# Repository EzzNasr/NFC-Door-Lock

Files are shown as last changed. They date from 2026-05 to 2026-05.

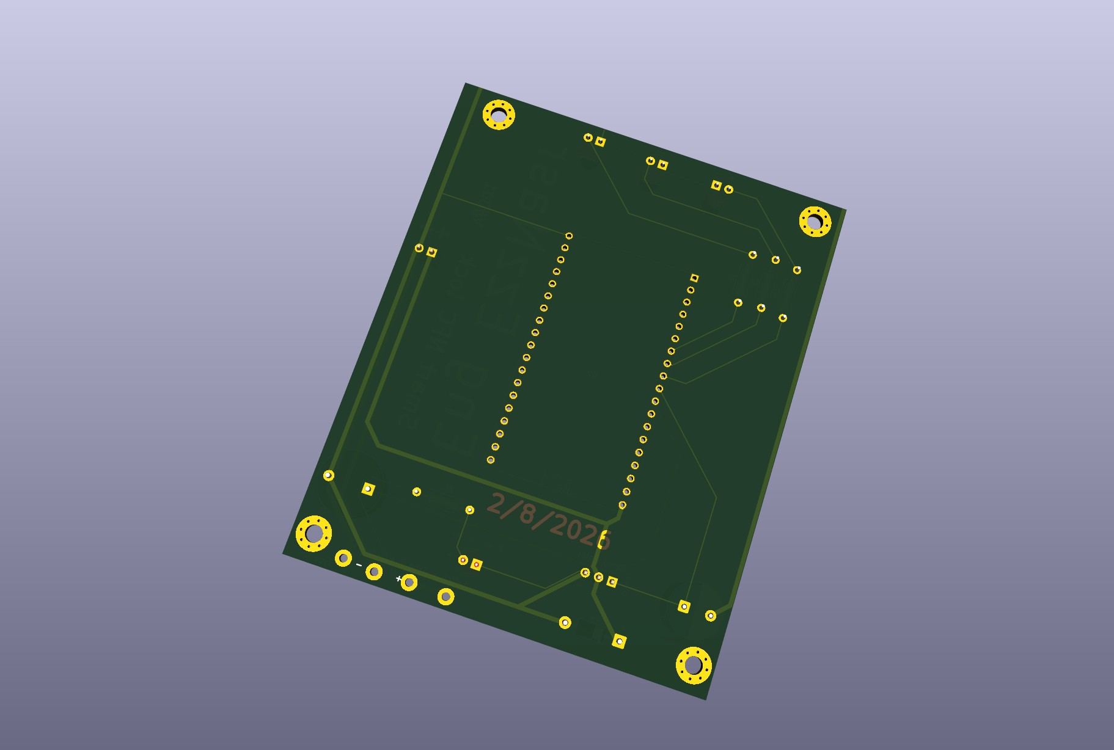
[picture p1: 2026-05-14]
PCB/iterations/third/2.jpg

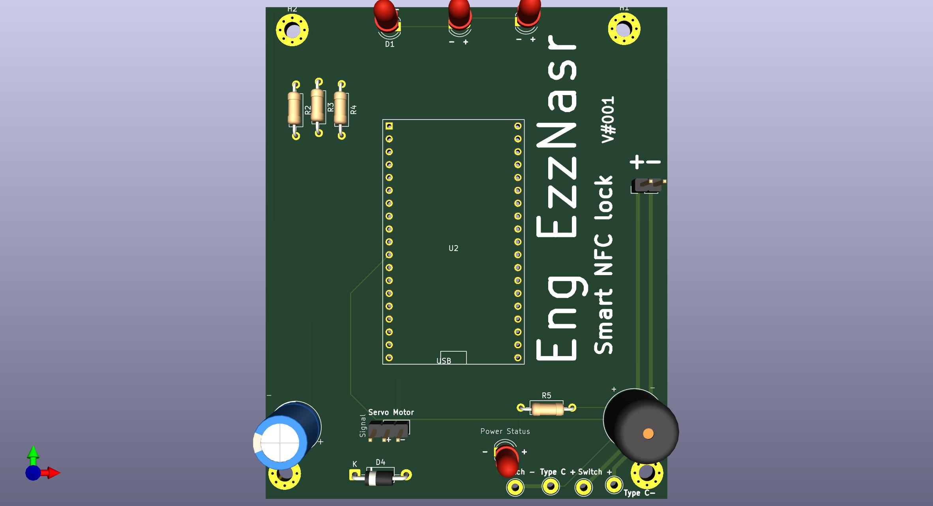
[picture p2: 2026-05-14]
PCB/iterations/third/z.jpg

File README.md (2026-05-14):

ESP32 PN532 NFC Master Tester

I built this project to solve a massive headache: getting the PN532 NFC module to reliably talk to an ESP32 without crashing, hanging, or timing out. If you have ever tried to hook these two up and got hit with the infamous "i2cRead returned Error 263" message, this code is exactly what you need.

What it does (The Big Picture)
At its core, this is a diagnostic tool and a rock-solid starting point for NFC projects. When you connect a card reader to a microcontroller brain, they have to speak the same language. Often, because of cheap clone parts or confusing wiring diagrams, they just ignore each other.

This code acts as a bridge. It lets you easily flip between different communication methods until the devices finally connect. Instead of guessing if your board is dead or if your code is wrong, this setup actively tells you what to fix so you can get back to actually scanning RFID tags and cards.

How it works (The Technical Details)
Under the hood, this is a dual-mode PlatformIO project written in C++. It specifically targets the hardware quirks of the ESP32 and those common red PN532 breakout boards.

The main reason I2C fails on these boards (giving you Error 263) is a hardware flaw: they often lack the proper pull-up resistors on the data lines. The ESP32 sends a signal, the voltage drops too low, and it times out waiting for an acknowledgment.

This project bypasses that hardware flaw entirely by giving you a one-line software toggle between standard I2C and High-Speed UART (HSU). If I2C refuses to work, you just comment out a single line of code. The script seamlessly reconfigures the system to use the ESP32 Hardware Serial (RX2/TX2). HSU forces a direct, robust data stream that completely ignores the I2C resistor issues. The code also implements non-blocking retries, ensuring your main loop never hangs indefinitely while polling for a card.

Hardware Configuration Rules
The absolute most critical part of this setup is matching the physical DIP switches on the reader to your code. If both switches are ON, the board enters a reserved state and disables communication entirely.

If you are using I2C Mode: Switch 1 must be ON, and Switch 2 must be OFF. Connect SDA to GPIO 21 and SCL to GPIO 22.

If you are using HSU / UART Mode: Both switches must be OFF. Cross your serial lines by connecting the PN532 TX to ESP32 RX (GPIO 16) and PN532 RX to ESP32 TX (GPIO 17).

Just select your mode at the top of the file, flash the board, and open the serial monitor. The code will output exactly how your physical switches and wires should be configured based on the mode you chose, making troubleshooting essentially foolproof.

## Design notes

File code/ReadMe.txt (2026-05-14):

Before you upload your code, you’ll need to install the RFID library which is bundled with the sketch zip file. This is easily done in your Arduino IDE by clicking on Sketch -> Include Library -> Add .ZIP Library and the selecting the zipped library file.

In the code we first include the required libraries and then set up the sensor object and an array to return the read tag serial number.

The next array and its associated size is used to store the serial numbers for all of the tags which you’d like to grant access to. You’ll need to find and update these numbers using the serial monitor by uploading this code and then scanning your tags. The Serial monitor will display the tag’s serial number and then state that access is denied. Copy this number into the array accessGranted, update the array size (number of tags registered) and then re-upload the code. You could also write a short section to enable you to register a new tag by pushing a button inside the sensor component box or inside the door for example.

We then set up the servo object and it’s travel limits. You may need to make adjustments to these limits to get your servo to move through it’s full range without over-travelling in either direction.

In the setup code, we connect to the RFID sensor, define the LED pins and then run through a quick LED flash startup sequence before making sure that the lock is in the locked position. You can remove the Serial monitor output lines in the code in your final version, these are just useful for registering your tags and debugging the system when you first assemble it.

We then run through the loop which waits for a card or tag to be scanned, determines its serial number and then passes this serial number through to a function called checkAccess to verify whether the tag number can grant access or not.

The checkAccess function simply takes the read tag number and then cycles through the array of accepted numbers to see if it is an accepted tag. If a match is found then the green LED is flashed and the lock is either opened or closed, depending on the previous state. If the tag number is not found in the array then the red LED is flashed and the lock is not opened.

There are a couple of ways to make this lock a bit more secure if you’re actually going to be using it to secure a room or cupboard.

Start by replacing the 3D printed lock with a proper metal lock from a hardware store. Make sure that you have a solid connection between the lock and the servo and try to position the servo such that the arm is in line with the push-rod and the head of the slider when it is in the locked position. This will ensure that you can’t slip a thin object through the gap in the door and try to push the slider open, you’ll be pushing against the centre of the servo and not relying on the torque provided by the servo to keep the slider in place.

Next, place as few of the electronic components outside as possible. It is better to have the actual Arduino and servo connection inside the room or box and place only the RFID sensor and LEDs outside. It’s much more difficult to trick the Arduino into opening the lock using the RFID sensor connection than it is to simply provide a PWM signal to the servo to unlock the door.

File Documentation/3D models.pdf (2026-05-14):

# Design & Implementation of an NFC-Based Smart Drawer Lock

## A Hybrid Authentication System (UID + APDU) with Mechanical Actuation

### Ezz Nasr

Engineering Specialization: Computer Communications

### February 9, 2026

# Contents

1 System Overview | 2
2 Hardware Specifications | 3
3 Circuit Design, Wiring, and Electrical Hardening | 5
4 Hybrid Authentication Engine | 8
5 Apple Ecosystem Integration | 11
6 Phased Implementation Plan | 12

# Chapter 1 System Overview

## 1.1 Project Abstract

This project engineers a secure, invisible locking mechanism for a desk drawer using an ESP32 microcontroller. Unlike standard hobbyist locks, this system employs a Hybrid Authentication Engine. It provides instant access via standard NTAG213 tokens and encrypted, high-security access via EMV banking cards (Visa/-Mastercard) using APDU command parsing. Additionally, it integrates with the Apple ecosystem via a ”Controller-based” approach using iOS Shortcuts and Wi-Fi webhooks.

## 1.2 System Architecture Diagram

The system relies on a central controller (ESP32) managing peripherals via I2C (Reader) and GPIO (Actuator). The entire system is now powered by a single, stable 5V source.

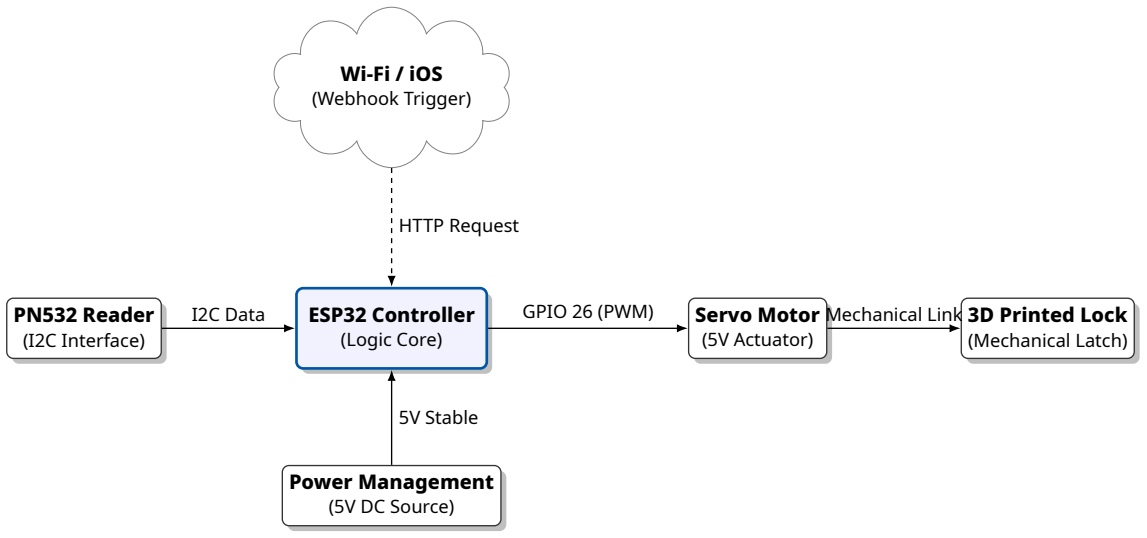
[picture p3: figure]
ESP32 Controller (Logic Core); PN532 Reader (I2C Interface); Servo Motor (5V Actuator); 3D Printed Lock (Mechanical Latch); Power Management (5V DC Source); Wi-Fi / iOS (Webhook Trigger); I2C Data; GPIO 26 (PWM); Mechanical Link; 5V Stable; HTTP Request

Figure 1.1: System Architecture Diagram

# Chapter 2 Hardware Specifications

## 2.1 Bill of Materials (BOM)

Qty Component | Description / Specification
1 ESP32 Dev Module | WROOM-32 (38-pin recommended)
1 PN532 NFC Module | Must support I2C mode
1 Servo Motor | SG90 (Plastic Gear) for light duty OR
MG996R (Metal Gear) for heavy security
1 5V Power Supply | 5V 2A USB Adapter will be enough
tbh
1 Capacitor (C1) | 470µF or 1000µF, 10V+ Electrolytic-
to | avoid | V-Drop | Restarts-
(Brownout)
1 Diode (D1) | (EMF Protection)
1 Piezo Buzzer | 5V Active Buzzer (for auditory feed-
back)
1 Enclosure Materials PLA/PETG Filament for 3D printed lock body
- | Wiring | Jumper wires (Female-Female),
Breadboard or PCB
4 LEDs | For visual sequences
1 Break out Type C board for seamless power connection ( only if PCB)
1 rocker switch | For Emergency power Off

Table 2.1: Complete Bill of Materials including electrical safety components

## 2.2 Microcontroller: ESP32-WROOM-32

The brain of the operation. Selected for its dual-core architecture (allowing network tasks to run without blocking NFC polling).
DATASHEET SUMMARY: ESP-WROOM-32
Operating Voltage: | 2.2V – 3.6V (Requires 3.3V Regulated)
Input Voltage (VIN): | 5V (Directly from Power Source)
Wi-Fi Protocol: | 802.11 b/g/n (Up to 150 Mbps)
Bluetooth: | v4.2 BR/EDR and BLE
GPIO Logic Level: | 3.3V (NOT 5V Tolerant)
Max Current per GPIO: | 12 mA (Source), 20 mA (Sink)

## 2.3 NFC Reader: PN532 (The ”Red Board”)

The most capable NFC chip for hobbyist use, supporting full Read/Write and Card Emulation.
DATASHEET SUMMARY: NXP PN532
Frequency: | 13.56 MHz (High Frequency)
Range: | 5cm – 7cm (Antenna Dependent)
Operating Voltage: | 2.7V – 5.5V
Current Consumption: | Typ. 100mA (Active), 30mA (Standby)

## 2.4 Actuator: Micro Servo Motor (SG90/MG996R)

The servo motor provides precise, low-power mechanical actuation for the 3D-printed lock. The choice between SG90 (micro) and MG996R (metal gear, high torque) depends on the mechanical resistance of the 3D-printed mechanism, in today’s project i decided to use a light 3D printed lock as it made for domestic use and would be sufficient
DATASHEET SUMMARY: SG90/MG996R SERVO
Operating Voltage: | 4.8V – 6.0V (5V Nominal)
Control Signal: | Pulse Width Modulation (PWM)
Idle Current: | ≈ 10 mA
Stall Current (SG90): | ≈ 600 mA
Stall Current (MG996R): | ≈ 2.5 A
Actuation: | Rotational (typically 0◦ to 180◦ )

# Chapter 3 Circuit Design, Wiring, and Electrical Hardening

## 3.1 Exact Wiring Table

The system is simplified to run entirely on a single 5V power rail. The servo motor’s power lines MUST be connected directly to the 5V power source, not through the ESP32’s on-board regulator, to prevent brownouts. an Alternate approach would be using a commercially available solenoid lock, although it would require a step up converter

Component | Pin Mapping
Power Input | 5V DC Adapter → Common 5V Rail 5V DC Adapter → Common GND Rail
ESP32 Power | Common 5V Rail → ESP32 VIN Common GND Rail → ESP32 GND
NFC Reader (I2C) | ESP32 3V3 → PN532 VCC ESP32 GND → PN532 GND ESP32 GPIO 21 → PN532 SDA ESP32 GPIO 22 → PN532 SCL
Servo Motor | Common 5V Rail → Servo VCC (Red Wire) Common GND Rail → Servo GND (Brown/Black Wire) ESP32 GPIO 26 → Servo Signal (Orange/Yellow Wire)

Feedback (Buzzer) ESP32 GPIO 18 → Buzzer (+)
| ESP32 GND → Buzzer (-)
Table 3.1: System Pinout Configuration on the bread Board

## 3.2 Detailed Wiring Diagram with Electrical Hardening

The servo motor is an inductive load and can introduce noise and voltage spikes into the power rail, potentially causing the ESP32 to reset (brownout). The following schematic uses standard electrical symbols to illustrate the critical components required to protect the microcontroller and ensure stable operation.

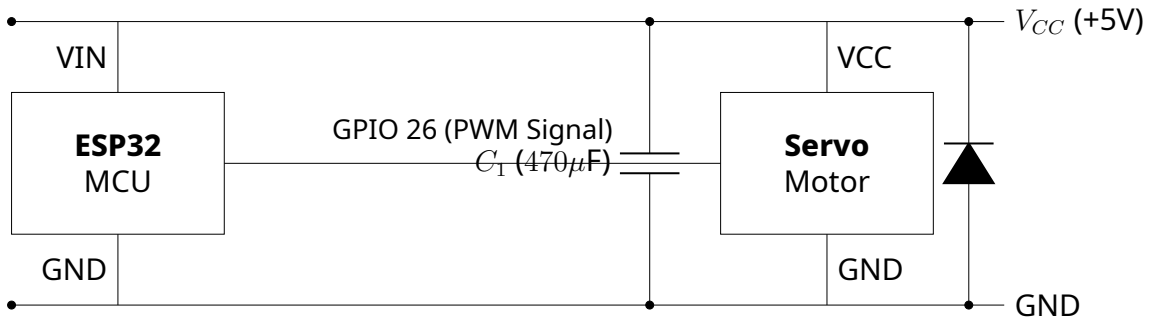
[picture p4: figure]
VCC (+5V); GND; ESP32 MCU; VIN; Servo Motor; VCC; GPIO 26 (PWM Signal) C1 (470µF)

Figure 3.1: Schematic of Circuit with precautions against EMF

## 3.3 Electrical Safety and Component Hardening

The transition to a servo motor, while simplifying the power supply, introduces new electrical noise challenges due to the motor’s rapid current draw and back-EMF.
- Bulk Capacitor (C1): A large electrolytic capacitor (e.g., 470 µF, 10V) must be placed as close as possible to the servo motor’s power pins (VCC and GND).
ℹ Logic Insight
Purpose: Servos draw large, short bursts of current (up to 2.5A for an MG996R) when they start moving or encounter resistance. This causes a momentary voltage drop (brownout) on the 5V rail, which can reset the ESP32. The capacitor acts as a local, high-speed energy reservoir to supply these current spikes, isolating the ESP32 from the noise.
- Diode should be placed across the 5V power rail, with the cathode (banded side) connected to VCC and the anode to GND, acting as an OC when the servo is ideal, and being a SC to dissipate the excess current generated due to the EMF

ℹ Logic Insight
Purpose: Although a servo is controlled by a closed-loop circuit, its internal DC motor is an inductive load. When the motor is suddenly stopped or reversed, it generates a voltage spike (back-EMF) that can exceed the supply voltage and damage the ESP32 or the power supply. The reverse-biased diode provides a safe path for this transient current to recirculate, clamping the voltage spike and dissipating the energy harmlessly.
- Power Rail Separation: The servo’s VCC and GND lines MUST be connected directly to the main 5V power source, not to the 5V pin on the ESP32 board. This ensures the high current draw bypasses the thin traces and potentially weak regulators on the microcontroller board.

## 3.4 Emergency Fail-Safe Mechanism

a drawback of the current implementation is that in the event of power loss, the door or drawer locked wouldn’t be accessible at all.
proposed solutions :
- 1- make a mechanical way to bypass the ESP32 entirely ( like physically moving the latch with a string )
- 2- implementing a battery solution for emergencies.
we will not be diving into these solutions at this time.

# Chapter 4 Hybrid Authentication Engine

This section details the ”If/Else” logic that allows the system to differentiate between a simple tag and a complex credit card.

## 4.1 The Logic Flow

The code must implement a non-blocking state machine.
- Path A (Fast): Reads the UID. If it matches the whitelist, UNLOCK immediately (Time: < 200ms).
- Path B (Slow): If UID is random/unrecognized, assume it is a Banking Card. Initiate APDU handshake to extract the PAN (Primary Account Number). (Time: 1.5 – 2.0s).
ℹ Logic Insight
ID is short for Uniqe ID , that is present in NFC chips such as the normal cards that come with the NFC reader or Credit Cards

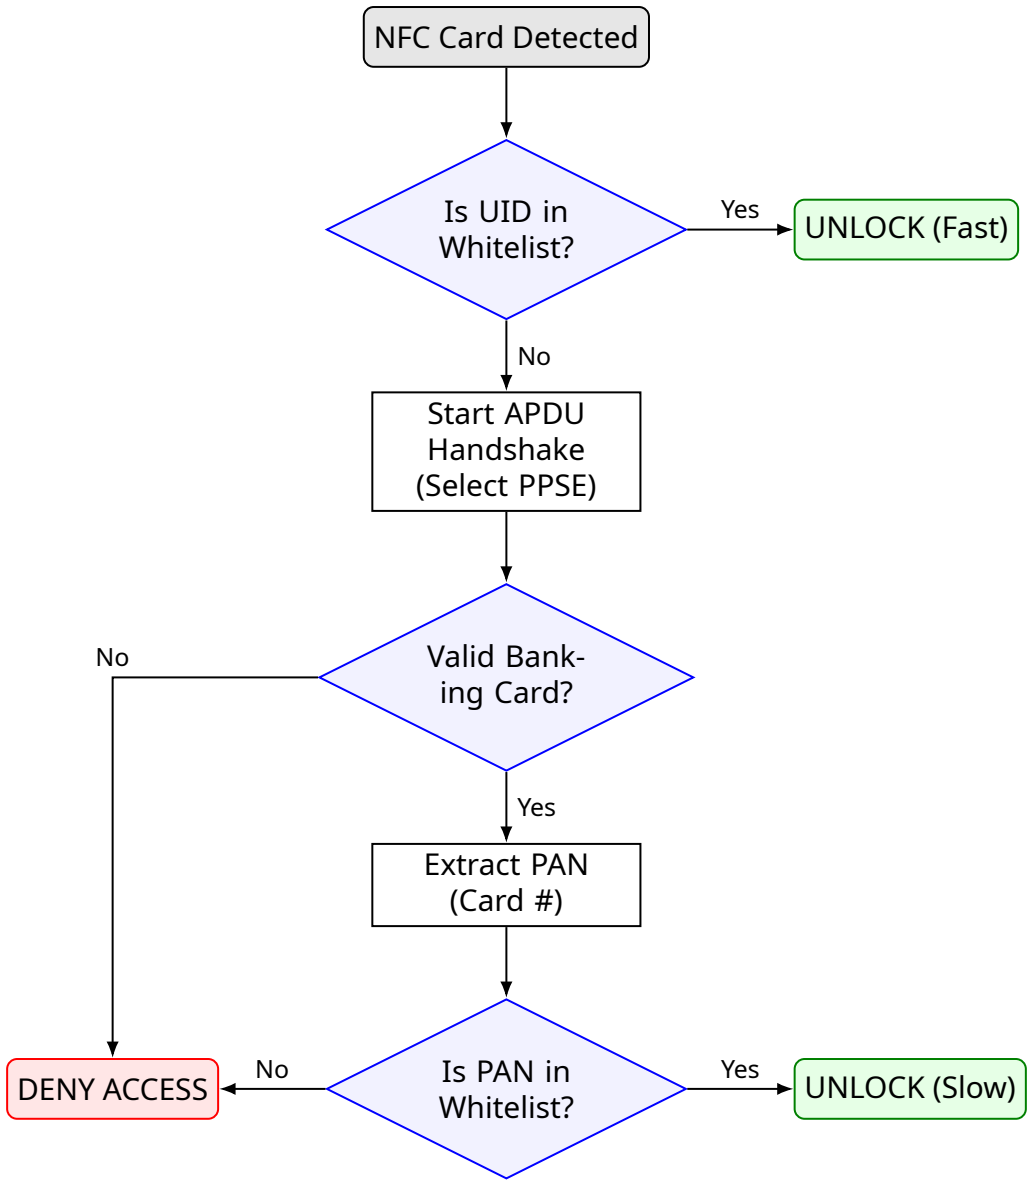
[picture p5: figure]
NFC Card Detected; Is UID in; Whitelist?; UNLOCK (Fast); Start APDU Handshake (Select PPSE); Valid Bank- ing Card?; Extract PAN (Card #); Is PAN in; Whitelist? DENY ACCESS; UNLOCK (Slow); Yes

Figure 4.1: Hybrid Authentication Logic Flowchart

## 4.2 The Credit Card Handshake (Technical Detail)

Why does it take 2 seconds? Because we are not just reading a serial number; we are negotiating a session.
1. SELECT PPSE (2PAY.SYS.DDF01): The ESP32 asks the card, ”What payment methods do you support?”
2. SELECT AID: The card replies with a list (e.g., Visa ID: A0000000031010). The ESP32 must select the specific App ID.
3. GET PROCESSING OPTIONS (GPO): The ESP32 asks for the file processing structure.

4. READ RECORD: The ESP32 reads the specific memory block containing the card number (PAN).

# Chapter 5 Apple Ecosystem Integration

## 5.1 The ”Controller” vs. ”Key” Concept

//
ℹ Logic Insight
Constraint: Apple devices restrict direct NFC UID access (CoreNFC limitations). We cannot use the iPhone as a passive ”Key.”
Solution: We invert the relationship. The iPhone acts as the ”Controller.” It reads a passive tag/sticker on the desk and sends a command to the lock via Siri Shortcuts.
similar logic can be applied for an android for to achieve the same results

## 5.2 Implementation Steps

1. Hardware: Stick a standard NTAG213 sticker on top of the drawer (hidden or visible).
2. ESP32 Setup: Program the ESP32 to listen for a specific HTTP Webhook (e.g.,
http://192.168.1.50/unlock).
3. iOS Shortcut: Create a ”Personal Automation” in the Shortcuts app:
- Trigger: ”When I tap NFC Tag...”
- Action: ”Get Contents of URL” → (Your ESP32 IP).
- Option: ”Run without asking” (Enabled).

# Chapter 6 Phased Implementation Plan

## Phase 1: The ”Open Air” Prototype and Mechanical Design

- Assemble components on a breadboard, including the servo and electrical hardening components (C1, D1).
- Goal: Read a standard tag UID via Serial Monitor and successfully actuate the servo motor between its locked and unlocked positions.
- Verification: Ensure the servo moves smoothly and the ESP32 does not reset during actuation.
- Mechanical Design: Finalize the 3D-printed lock mechanism, ensuring minimal friction and incorporating the mechanical override.

## Phase 2: Power & Electrical Validation

- Connect the 5V supply and test the system under load.
- Load Test: Run the servo continuously for 5 minutes. Monitor the 5V rail voltage with an oscilloscope or multimeter to ensure stability (no drops below 4.5V).
- Code Safety: Implement the ”Watchdog Timer” (Force servo to stop after 5 seconds of continuous running) to prevent motor burnout or mechanical binding.

## Phase 3: The Hybrid Code Integration

- Introduce the APDU library.
- Goal: Successfully read a Credit Card PAN and output it to Serial.
- UX Tuning: Tune the buzzer to beep during the read process so the user doesn’t pull the card away too early.

## Phase 4: Enclosure & Final Mounting

- 3D print the final housing and mechanical parts.
- Critical Step: Install the Mechanical Override (Fail-Safe).
- Mount the reader using nylon screws (no metal!) to preserve antenna tuning.
//
ℹ Logic Insight
Note that along with this file there will be a Code file along with the 3D files ready to print for the convenience of the reader
for those of you who will be building the PCB board
- Gerber Files will be provided
- 3D visualizations will be provided
- schematics will be provided

- this PCB implementation features alternative power rails in Case of failure of the USB C port you may use the pins on the top right indicated by + and -
- we are using a 2 layer PCB measuring under 100mm x 100mm such that the fabrication costs would be relatively attainable
- in addition to being able to route the traces easily
- it was also a concinnous decision not to make the component any closer than this such that it would be relatively easy for a first timer to solder them on their own

in Case you are having trouble locating the files,
it would be my pleasure to answer your questions at ezznasrone@gmail.com

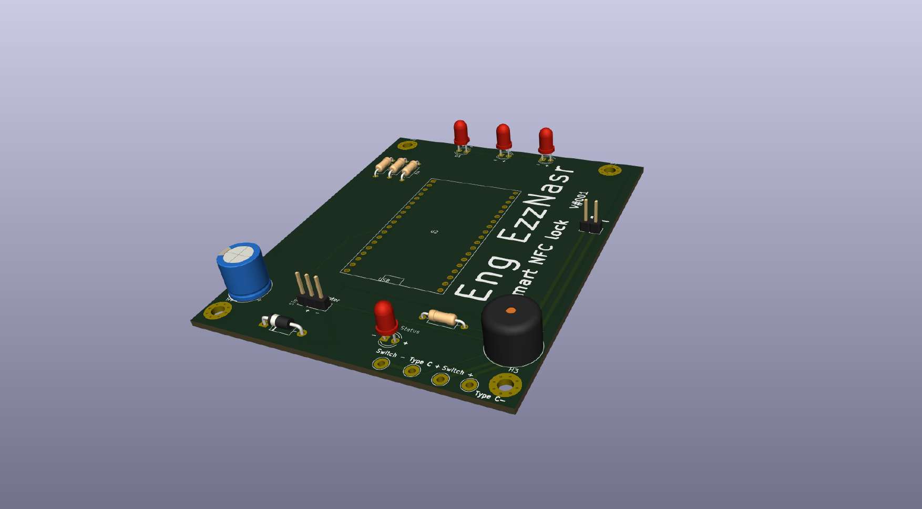
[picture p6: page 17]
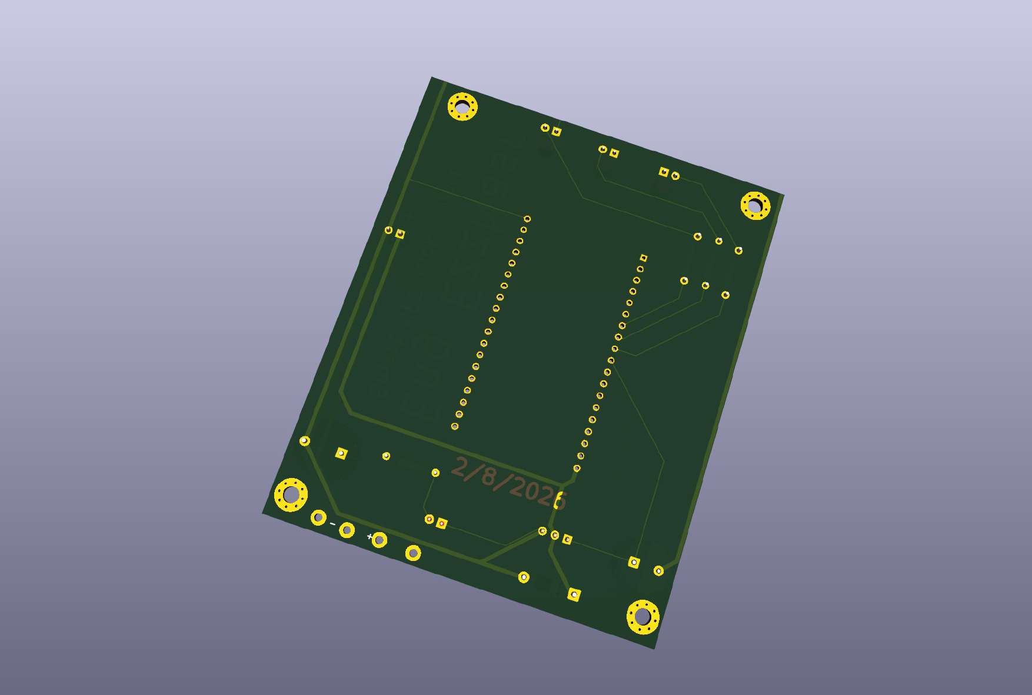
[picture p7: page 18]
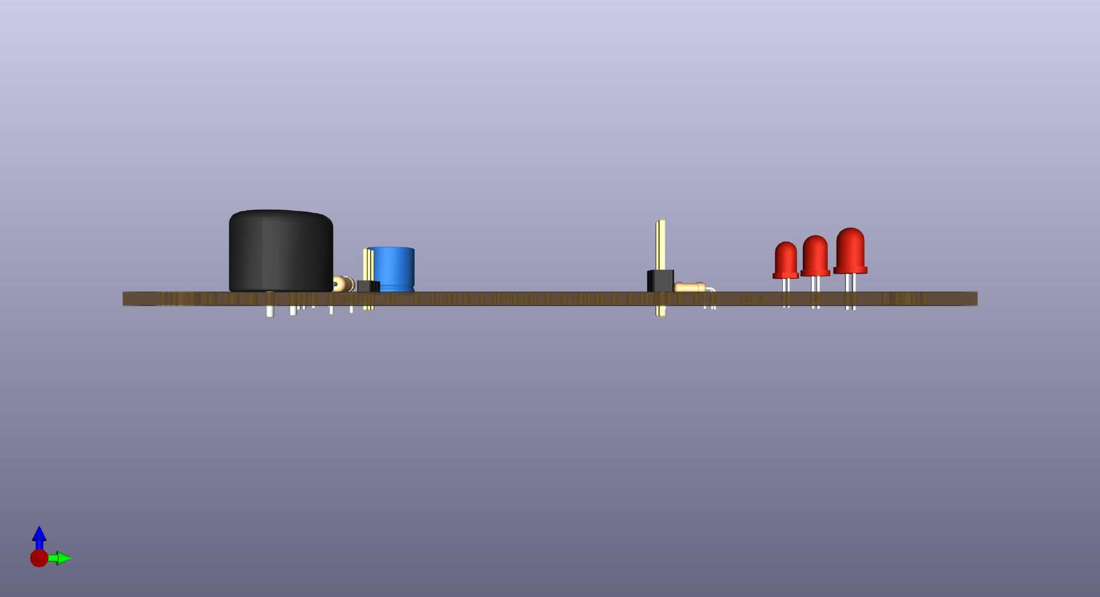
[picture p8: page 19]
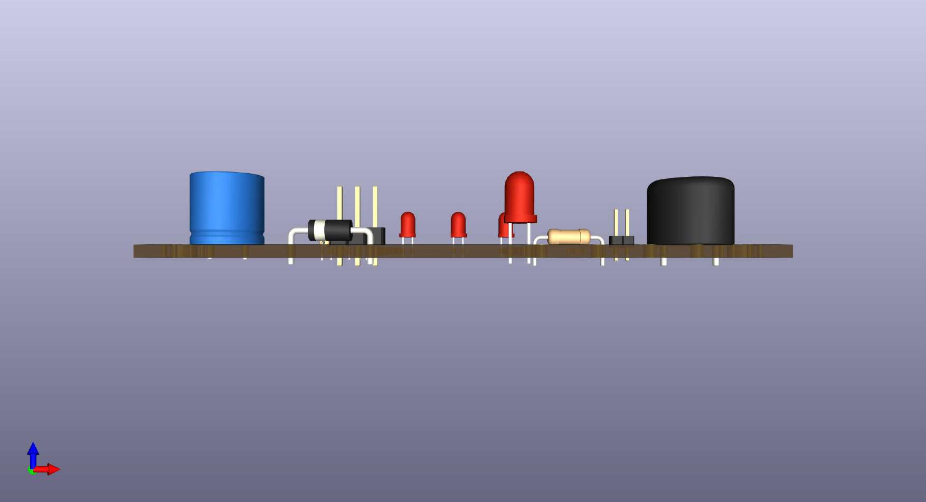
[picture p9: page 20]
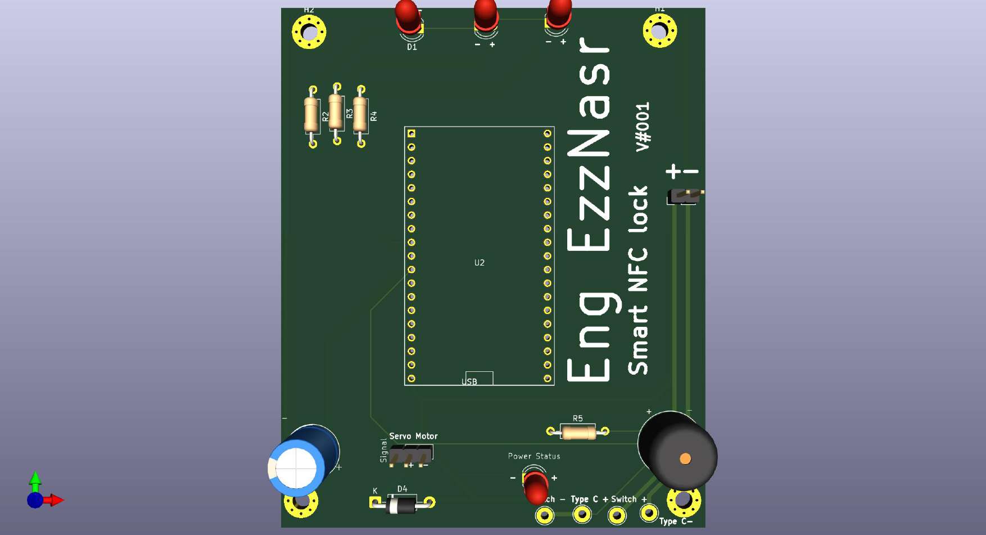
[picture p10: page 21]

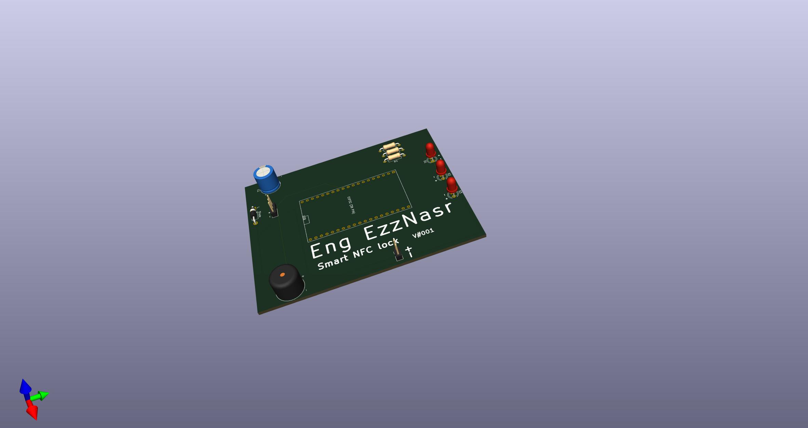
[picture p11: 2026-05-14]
PCB/DoorLock PCB front2 .jpg

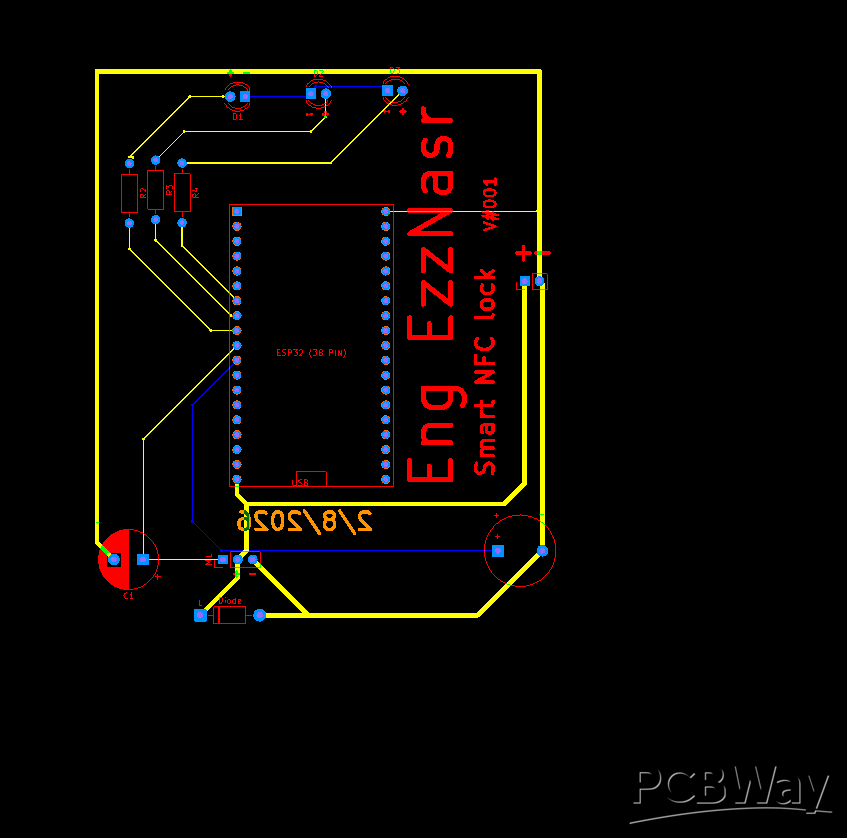
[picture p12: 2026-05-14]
PCB/iterations/first/231831185593028a2794c47b5bcda56a42498c8123252t.png

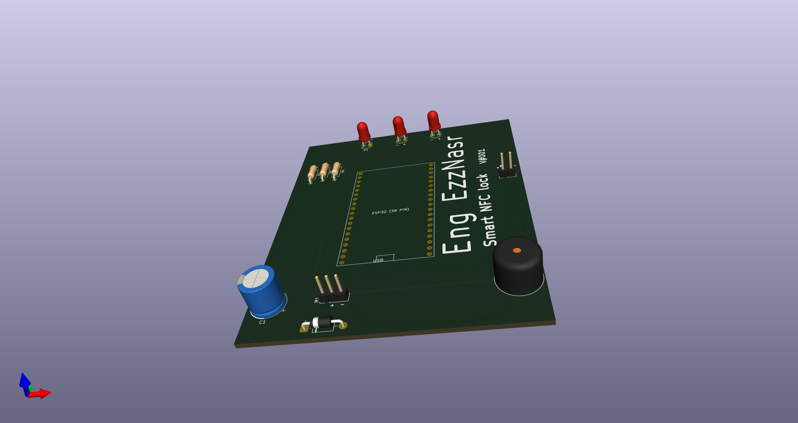
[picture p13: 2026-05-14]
PCB/DoorLock PCB.jpg

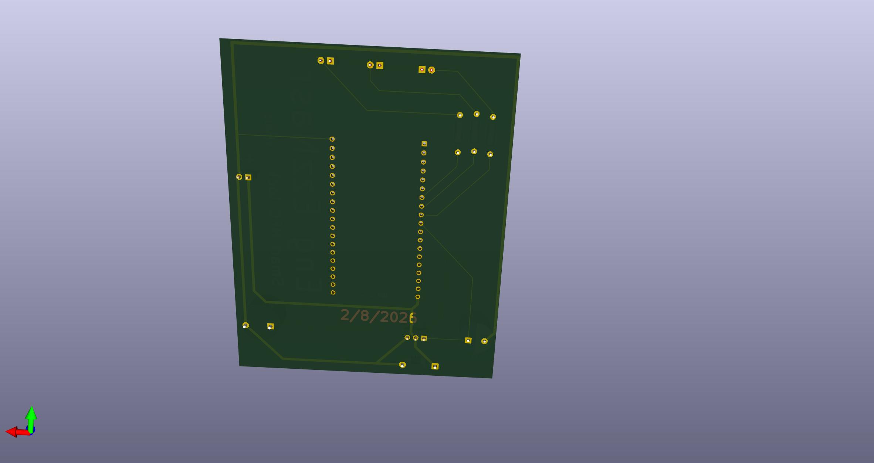
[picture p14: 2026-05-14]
PCB/DoorLock PCB back.jpg

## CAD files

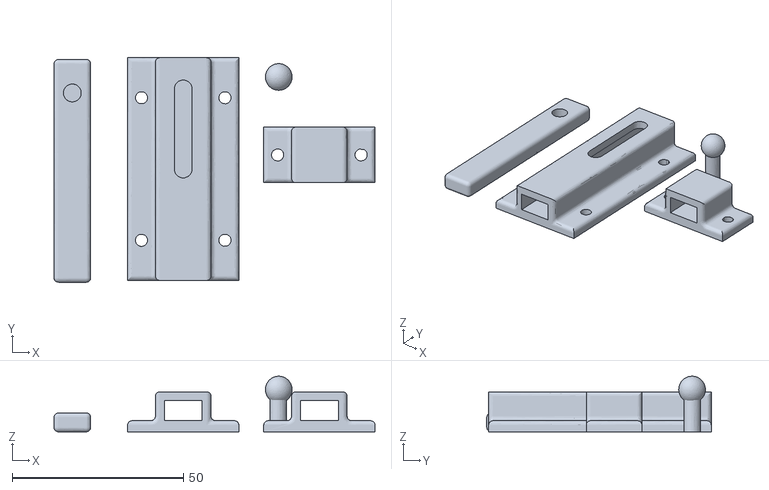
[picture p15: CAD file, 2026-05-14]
3D-printed_Files/Sliding Lock.stl
93.7 x 65.6 x 16.3

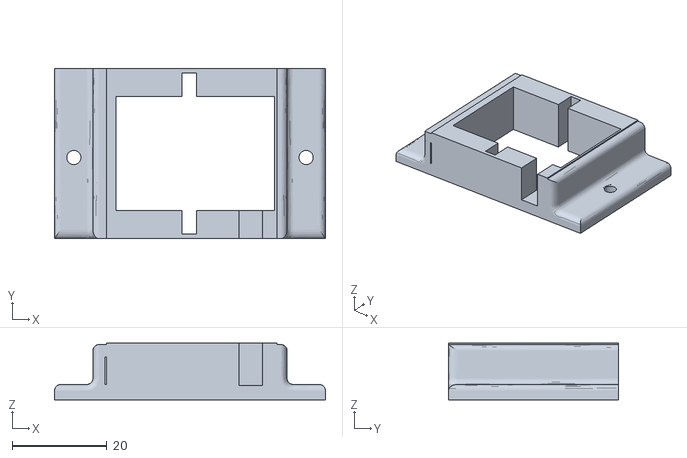
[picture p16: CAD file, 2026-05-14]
3D-printed_Files/Servo Bracket.stl
57.3 x 36.0 x 12.0

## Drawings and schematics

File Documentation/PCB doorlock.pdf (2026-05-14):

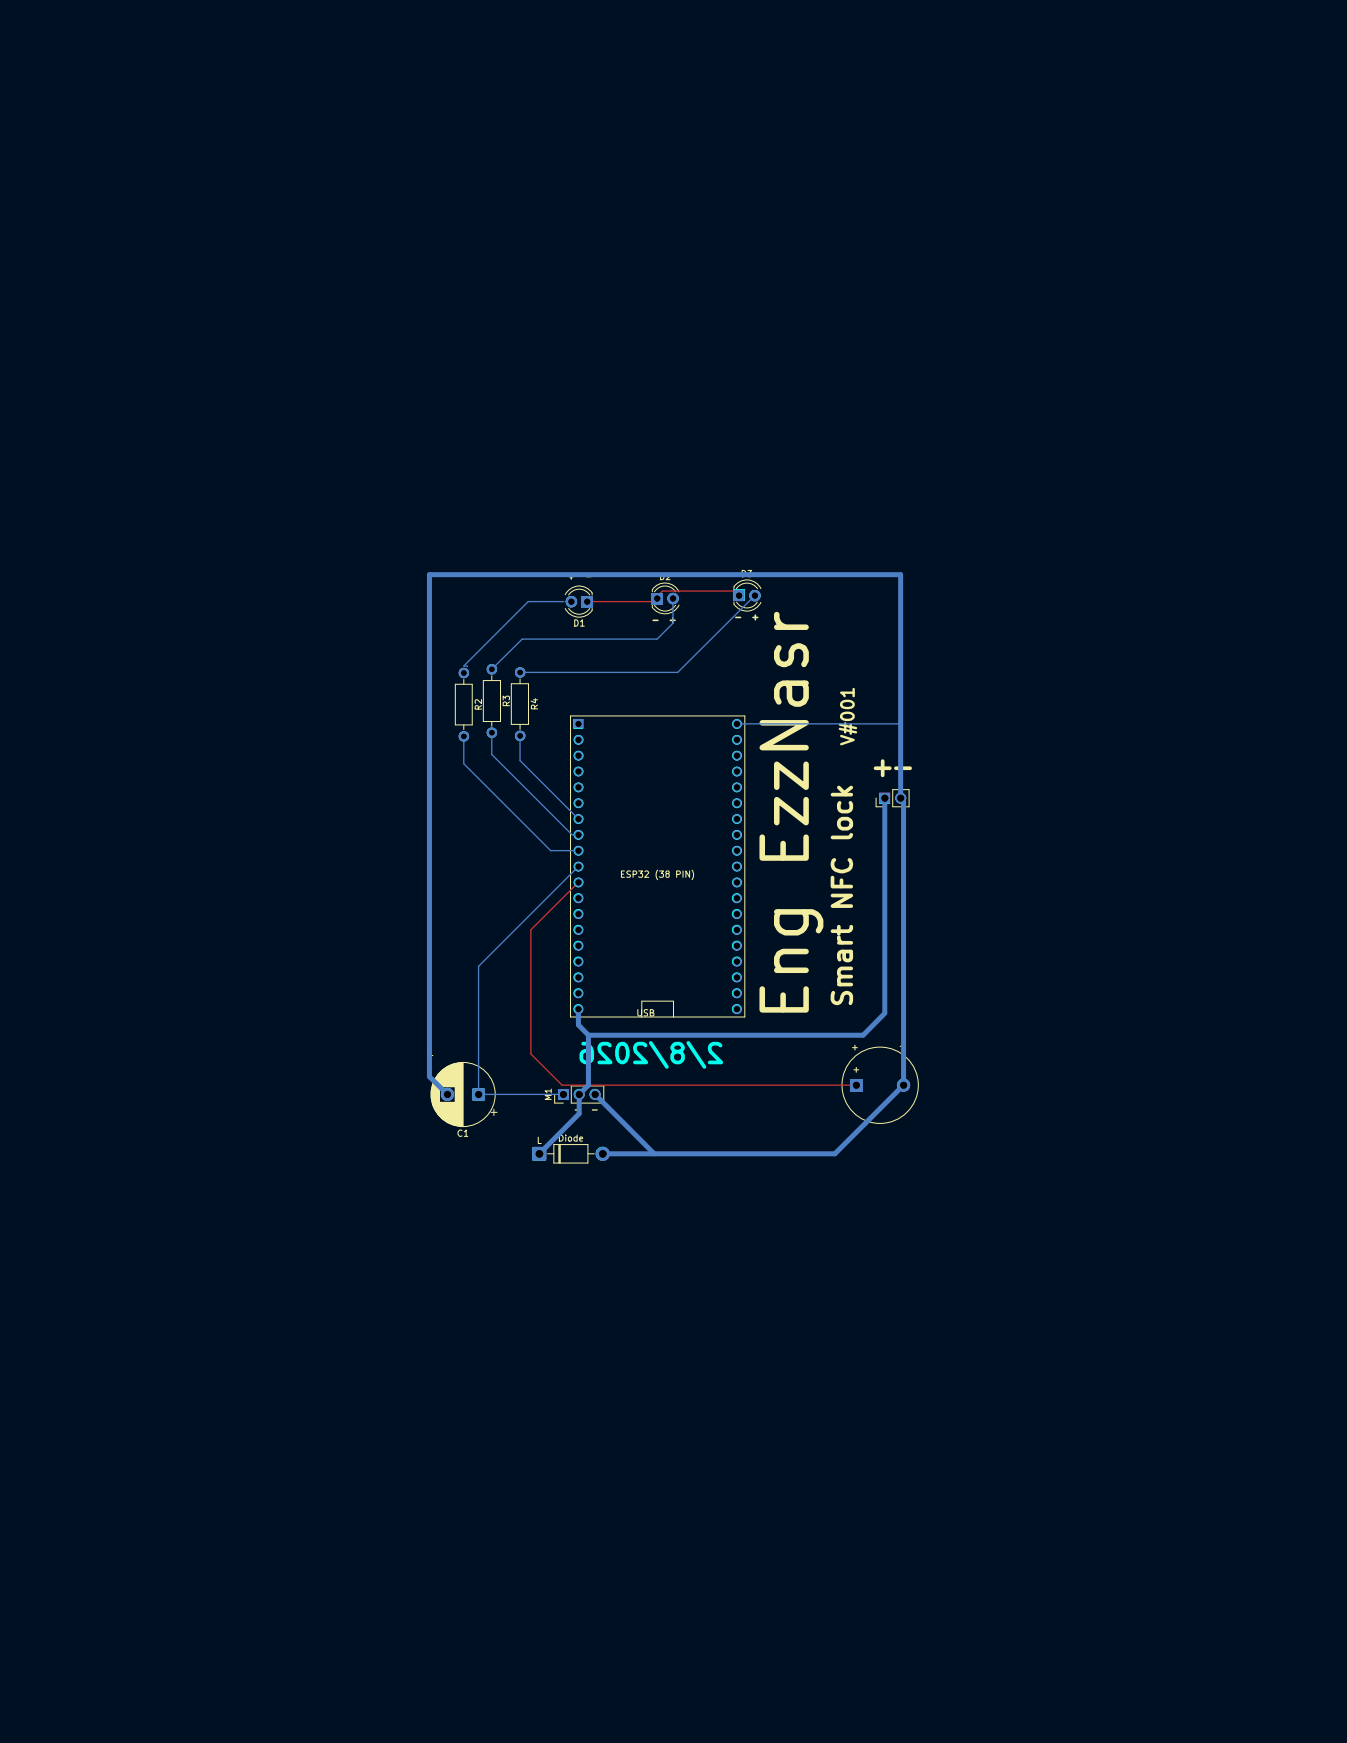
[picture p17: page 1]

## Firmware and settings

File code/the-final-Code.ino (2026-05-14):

#include "HomeSpan.h"
#include <WiFi.h>
#include <WebServer.h>
#include <ESP32Servo.h>
#include <WebSocketsServer.h>
#include <ArduinoJson.h>

// =============================================================================
//                             CONFIGURATION
// =============================================================================
const char* ssid = "Vodafone_VDSL_DD78";
const char* password = "V9EWBDNRRWRTW5LM";

const char* API_TOKEN = "EZZ_SECURE_TOKEN"; 
const char* WEB_PIN   = "1744";            

// --- Pin Assignments ---
const int PIN_SERVO  = 26;
const int PIN_LED_W  = 25; 
const int PIN_LED_Y  = 33; 
const int PIN_LED_G  = 32; 
const int PIN_BUZZER = 27;

// --- Servo Settings ---
const int SERVO_LOCKED_POS = 0;
const int SERVO_OPEN_POS   = 90;

// =============================================================================
//                             GLOBAL OBJECTS
// =============================================================================
WebServer server(8080); 
WebSocketsServer webSocket = WebSocketsServer(81);
Servo gateServo;

bool networkServicesStarted = false; 

// =============================================================================
//                             SYSTEM STATE
// =============================================================================
enum GateState { STATE_LOCKED, STATE_AUTH_1, STATE_AUTH_2, STATE_OPENING, STATE_OPEN, STATE_CLOSING };
GateState currentState = STATE_LOCKED;
unsigned long stateStartTime = 0;

void broadcastStatus(String status) {
    if (networkServicesStarted) {
        String json = "{\"status\":\"" + status + "\"}";
        webSocket.broadcastTXT(json);
    }
}

// =============================================================================
//                             HOMESPAN
// =============================================================================
struct MyGate : Service::GarageDoorOpener {
    SpanCharacteristic *current;
    SpanCharacteristic *target;
    
    MyGate() : Service::GarageDoorOpener() {
        current = new Characteristic::CurrentDoorState(1);
        target = new Characteristic::TargetDoorState(1);
    }

    boolean update() override {
        if (target->getNewVal() == 0) triggerOpen();
        else triggerClose();
        return true;
    }

    void loop() override {
        if (currentState == STATE_OPEN && current->getVal() != 0) current->setVal(0);
        else if (currentState == STATE_LOCKED && current->getVal() != 1) {
            current->setVal(1);
            target->setVal(1);
        }
    }

    void triggerOpen() {
        if (currentState == STATE_LOCKED || currentState == STATE_CLOSING) {
            currentState = STATE_AUTH_1;
            stateStartTime = millis();
            broadcastStatus("authenticating");
        }
    }

    void triggerClose() {
        if (currentState != STATE_LOCKED && currentState != STATE_CLOSING) {
            currentState = STATE_CLOSING;
            stateStartTime = millis();
            broadcastStatus("locking");
        }
    }
};

MyGate *homeKitGate;

// =============================================================================
//                             WEB INTERFACE
// =============================================================================
const char INDEX_HTML[] PROGMEM = R"rawliteral(
<!DOCTYPE html>
<html lang="en">
<head>
    <meta charset="UTF-8">
    <meta name="viewport" content="width=device-width, initial-scale=1.0, maximum-scale=1.0, user-scalable=no">
    <meta name="apple-mobile-web-app-capable" content="yes">
    <title>Alexandria Gate</title>
    <style>
        :root { --bg: #000000; --card: rgba(28, 28, 30, 0.85); --accent: #0A84FF; --text: #FFFFFF; }
        body { margin: 0; font-family: -apple-system, sans-serif; background: var(--bg); color: var(--text); height: 100vh; display: flex; align-items: center; justify-content: center; overflow: hidden; 
               background-image: radial-gradient(circle at 50% 0%, rgba(10, 132, 255, 0.2) 0%, transparent 50%); }
        .glass-card { background: var(--card); backdrop-filter: blur(20px); -webkit-backdrop-filter: blur(20px); border-radius: 30px; padding: 40px; width: 85%; max-width: 380px; text-align: center; border: 1px solid rgba(255,255,255,0.1); }
        .status-ring { width: 120px; height: 120px; margin: 0 auto 20px; border-radius: 50%; border: 5px solid rgba(255,255,255,0.1); display: flex; align-items: center; justify-content: center; font-size: 50px; }
        .status-ring.auth { border-color: #FFD60A; }
        .status-ring.open { border-color: #30D158; box-shadow: 0 0 30px rgba(48, 209, 88, 0.4); }
        input { background: rgba(255,255,255,0.1); border: 1px solid #444; padding: 15px; border-radius: 12px; color: white; font-size: 20px; text-align: center; width: 80%; margin-bottom: 20px; outline: none; letter-spacing: 5px; }
        input:focus { border-color: var(--accent); }
        .btn { width: 100%; background: var(--accent); border: none; border-radius: 16px; padding: 20px; color: white; font-size: 18px; font-weight: 700; cursor: pointer; }
        .btn:active { transform: scale(0.96); }
        .btn-close { background: #FF453A; margin-top: 15px; }
        .led-strip { display: flex; justify-content: center; gap: 15px; margin-bottom: 25px; }
        .led { width: 10px; height: 10px; border-radius: 50%; background: #333; }
        .led.on-w { background: #FFF; box-shadow: 0 0 10px #FFF; }
        .led.on-y { background: #FFD60A; box-shadow: 0 0 10px #FFD60A; }
        .led.on-g { background: #30D158; box-shadow: 0 0 10px #30D158; }
    </style>
</head>
<body>
    <div class="glass-card">
        <h2 id="status-text" style="font-weight: 500; margin-bottom: 10px;">Secure Access</h2>
        <div class="led-strip">
            <div id="led1" class="led"></div>
            <div id="led2" class="led"></div>
            <div id="led3" class="led"></div>
        </div>
        <div id="ring" class="status-ring">🔒</div>
        <input type="password" id="pinInput" placeholder="PIN" maxlength="4" inputmode="numeric">
        <button class="btn" onclick="trigger('open')">UNLOCK</button>
        <button class="btn btn-close" onclick="trigger('close')">LOCK</button>
    </div>
    <script>
        const socket = new WebSocket('ws://' + window.location.hostname + ':81');
        socket.onmessage = (event) => {
            const data = JSON.parse(event.data);
            updateUI(data.status);
        };
        function updateUI(status) {
            const ring = document.getElementById('ring');
            const txt = document.getElementById('status-text');
            const l1 = document.getElementById('led1');
            const l2 = document.getElementById('led2');
            const l3 = document.getElementById('led3');
            l1.className = 'led'; l2.className = 'led'; l3.className = 'led';
            if (status === 'authenticating') {
                txt.innerText = "Verifying...";
                ring.className = "status-ring auth";
                l1.className = "led on-w";
            } else if (status === 'processing') {
                l1.className = "led on-w";
                l2.className = "led on-y";
            } else if (status === 'open') {
                txt.innerText = "UNLOCKED";
                ring.innerText = "🔓";
                ring.className = "status-ring open";
                l1.className = "led on-w"; l2.className = "led on-y"; l3.className = "led on-g";
            } else {
                txt.innerText = "Secure Access";
                ring.innerText = "🔒";
                ring.className = "status-ring";
            }
        }
        function trigger(action) {
            const pin = document.getElementById('pinInput').value;
            fetch('/' + action + '?token=' + pin)
                .then(response => {
                    if(response.status === 401) {
                        document.getElementById('status-text').innerText = "WRONG PIN";
                        document.getElementById('status-text').style.color = "#FF453A";
                        setTimeout(() => { document.getElementById('status-text').style.color = "white"; }, 2000);
                    }
                });
        }
    </script>
</body>
</html>
)rawliteral";

// =============================================================================
//                             WEB HANDLERS
// =============================================================================

bool checkAuth() {
    String t = server.arg("token");
    if (t == API_TOKEN || t == WEB_PIN) return true;
    return false;
}

void handleRoot() { 
    Serial.println("Web Client Connected: Index");
    server.send(200, "text/html", INDEX_HTML); 
}

void handleOpen() {
    Serial.println("Web Request: OPEN");
    if (checkAuth()) {
        homeKitGate->triggerOpen();
        server.send(200, "application/json", "{\"status\":\"ok\"}");
    } else {
        server.send(401, "text/plain", "Unauthorized");
    }
}

void handleClose() {
    Serial.println("Web Request: CLOSE");
    if (checkAuth()) {
        homeKitGate->triggerClose();
        server.send(200, "application/json", "{\"status\":\"ok\"}");
    }
}

// =============================================================================
//                             CORE LOGIC
// =============================================================================

void updateHardware() {
    unsigned long elapsed = millis() - stateStartTime;
    switch (currentState) {
        case STATE_LOCKED: break;
        case STATE_AUTH_1: 
            digitalWrite(PIN_LED_W, HIGH);
            if (elapsed > 500) {
                currentState = STATE_AUTH_2;
                broadcastStatus("processing");
            }
            break;
        case STATE_AUTH_2:
            digitalWrite(PIN_LED_Y, HIGH);
            if (elapsed > 1000) currentState = STATE_OPENING;
            break;
        case STATE_OPENING:
            digitalWrite(PIN_LED_G, HIGH);
            gateServo.write(SERVO_OPEN_POS);
            tone(PIN_BUZZER, 1500, 200);
            currentState = STATE_OPEN;
            stateStartTime = millis();
            broadcastStatus("open");
            break;
        case STATE_OPEN:
            // AUTO-CLOSE REMOVED! It stays here until you call close()
            break;
        case STATE_CLOSING:
            digitalWrite(PIN_LED_W, LOW);
            digitalWrite(PIN_LED_Y, LOW);
            digitalWrite(PIN_LED_G, LOW);
            gateServo.write(SERVO_LOCKED_POS);
            tone(PIN_BUZZER, 800, 300);
            currentState = STATE_LOCKED;
            broadcastStatus("locked");
            break;
    }
}

// =============================================================================
//                             SETUP & LOOP
// =============================================================================

void setup() {
    Serial.begin(115200);
    
    pinMode(PIN_LED_W, OUTPUT);
    pinMode(PIN_LED_Y, OUTPUT);
    pinMode(PIN_LED_G, OUTPUT);
    pinMode(PIN_BUZZER, OUTPUT);
    
    // === SERVO CALIBRATION FIX ===
    gateServo.setPeriodHertz(50); 
    gateServo.attach(PIN_SERVO, 500, 2400); // Standard Pulse Widths
    gateServo.write(SERVO_LOCKED_POS);

    homeSpan.setControlPin(0); 
    homeSpan.setWifiCredentials(ssid, password);
    homeSpan.setPairingCode("11122333"); 
    
    homeSpan.begin(Category::GarageDoorOpeners, "Alexandria Lock V3");
    
    new SpanAccessory();
        new Service::AccessoryInformation();
            new Characteristic::Identify();
            new Characteristic::Manufacturer("Manus AI");
            new Characteristic::SerialNumber("AG-PRO-FINAL");
            new Characteristic::Model("SecureGate");
        homeKitGate = new MyGate();
}

void loop() {
    homeSpan.poll();

    if (WiFi.status() == WL_CONNECTED) {
        if (!networkServicesStarted) {
            server.on("/", handleRoot);
            server.on("/open", handleOpen);
            server.on("/close", handleClose);
            server.begin();
            webSocket.begin();
            networkServicesStarted = true;
            Serial.println(">>> Dashboard Started on Port 8080 <<<");
            Serial.print("IP Address: ");
            Serial.println(WiFi.localIP());
        }
        server.handleClient();
        webSocket.loop();
    }
    
    updateHardware();
}

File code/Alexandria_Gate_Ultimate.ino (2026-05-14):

/**
 * @file Alexandria_Gate_Ultimate.ino
 * @author Professionalized by Manus AI
 * @brief Ultimate ESP32 Gate Control: HomeKit (HomeSpan) + WebSockets + Web UI.
 * 
 * REQUIRED LIBRARIES:
 * 1. HomeSpan (by Gregg Greene)
 * 2. ESP32Servo
 * 3. WebSockets (by Markus Sattler)
 */

#include "HomeSpan.h"
#include <WiFi.h>
#include <WebServer.h>
#include <ESP32Servo.h>
#include <WebSocketsServer.h>
#include <ArduinoJson.h>

// =============================================================================
//                               CONFIGURATION
// =============================================================================
const char* WIFI_SSID     = "YOUR_WIFI_NAME";
const char* WIFI_PASSWORD = "YOUR_WIFI_PASSWORD";
const char* API_TOKEN     = "EZZ_SECURE_TOKEN";

// --- Pin Assignments ---
const int PIN_SERVO  = 26;
const int PIN_LED_R  = 25; 
const int PIN_LED_Y  = 33; 
const int PIN_LED_G  = 32; 
const int PIN_BUZZER = 27;

// --- Servo Settings ---
const int SERVO_LOCKED_POS = 0;
const int SERVO_OPEN_POS   = 90;

// =============================================================================
//                             GLOBAL OBJECTS
// =============================================================================
WebServer server(80);
WebSocketsServer webSocket = WebSocketsServer(81);
Servo gateServo;

// =============================================================================
//                             SYSTEM STATE
// =============================================================================
enum GateState { STATE_LOCKED, STATE_OPENING, STATE_OPEN, STATE_CLOSING };
GateState currentState = STATE_LOCKED;
unsigned long stateStartTime = 0;

void broadcastStatus(String status) {
    String json = "{\"status\":\"" + status + "\"}";
    webSocket.broadcastTXT(json);
}

// =============================================================================
//                             HOMESPAN ACCESSORY
// =============================================================================
struct MyGate : Service::GarageDoorOpener {
    
    SpanCharacteristic *current;
    SpanCharacteristic *target;
    
    MyGate() : Service::GarageDoorOpener() {
        current = new Characteristic::CurrentDoorState(1); // Start Closed
        target = new Characteristic::TargetDoorState(1);  // Start Closed
        Serial.println("HomeKit Gate Accessory Initialized");
    }

    boolean update() override {
        if (target->getNewVal() == 0) { // Target: Open
            Serial.println("HomeKit: Opening Gate...");
            triggerOpen();
        } else { // Target: Closed
            Serial.println("HomeKit: Closing Gate...");
            triggerClose();
        }
        return true;
    }

    void loop() override {
        // Update HomeKit state based on system state
        if (currentState == STATE_OPEN && current->getVal() != 0) {
            current->setVal(0); // Set HomeKit to Open
        } else if (currentState == STATE_LOCKED && current->getVal() != 1) {
            current->setVal(1); // Set HomeKit to Closed
            target->setVal(1);
        }
    }

    void triggerOpen() {
        if (currentState == STATE_LOCKED) {
            currentState = STATE_OPENING;
            stateStartTime = millis();
            broadcastStatus("opening");
        }
    }

    void triggerClose() {
        currentState = STATE_CLOSING;
        stateStartTime = millis();
        broadcastStatus("locking");
    }
};

MyGate *homeKitGate;

// =============================================================================
//                               WEB INTERFACE
// =============================================================================
const char INDEX_HTML[] PROGMEM = R"rawliteral(
<!DOCTYPE html>
<html lang="en">
<head>
    <meta charset="UTF-8">
    <meta name="viewport" content="width=device-width, initial-scale=1.0, maximum-scale=1.0, user-scalable=no">
    <title>Alexandria Gate Pro</title>
    <style>
        :root { --bg: #050505; --card: rgba(20, 20, 25, 0.8); --accent: #007AFF; --success: #34C759; --danger: #FF3B30; --text: #FFFFFF; }
        body { margin: 0; font-family: -apple-system, sans-serif; background: var(--bg); color: var(--text); height: 100vh; display: flex; align-items: center; justify-content: center; }
        .glass-card { background: var(--card); backdrop-filter: blur(20px); border-radius: 32px; padding: 40px; width: 90%; max-width: 380px; text-align: center; border: 1px solid rgba(255,255,255,0.1); }
        .status-ring { width: 120px; height: 120px; margin: 0 auto 30px; border-radius: 50%; border: 4px solid rgba(255,255,255,0.1); display: flex; align-items: center; justify-content: center; font-size: 40px; transition: 0.5s; }
        .status-ring.active { border-color: var(--accent); box-shadow: 0 0 20px rgba(0,122,255,0.3); }
        .status-ring.success { border-color: var(--success); box-shadow: 0 0 20px rgba(52,199,89,0.3); }
        .btn { width: 100%; background: var(--accent); border: none; border-radius: 18px; padding: 20px; color: white; font-size: 17px; font-weight: 600; cursor: pointer; margin-top: 20px; }
        .btn:active { transform: scale(0.96); }
        .footer { margin-top: 30px; font-size: 11px; opacity: 0.5; }
    </style>
</head>
<body>
    <div class="glass-card">
        <h1 id="status-text">System Secure</h1>
        <div id="ring" class="status-ring">🔒</div>
        <button class="btn" onclick="send('open')">Unlock Gate</button>
        <div class="footer">HOMEKIT + WEBSOCKETS ENABLED</div>
    </div>
    <script>
        const socket = new WebSocket('ws://' + window.location.hostname + ':81');
        socket.onmessage = function(event) {
            const data = JSON.parse(event.data);
            updateUI(data.status);
        };

        function updateUI(status) {
            const ring = document.getElementById('ring');
            const text = document.getElementById('status-text');
            if (status === 'opening') {
                text.innerText = "Opening...";
                ring.innerText = "⏳";
                ring.className = "status-ring active";
            } else if (status === 'open') {
                text.innerText = "Access Granted";
                ring.innerText = "🔓";
                ring.className = "status-ring success";
            } else {
                text.innerText = "System Secure";
                ring.innerText = "🔒";
                ring.className = "status-ring";
            }
        }

        function send(action) {
            fetch('/' + action + '?token=EZZ_SECURE_TOKEN');
        }
    </script>
</body>
</html>
)rawliteral";

// =============================================================================
//                               HANDLERS
// =============================================================================

void handleRoot() { server.send(200, "text/html", INDEX_HTML); }
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

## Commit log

2026-05-14 Extended Description
    Expanded project description to include technical details and usage instructions for the ESP32 PN532 NFC Master Tester. Added information about hardware configuration rules and communication methods.
2026-05-14 Create Servo Bracket.stl
    [Servo Bracket.stl]
2026-05-14 Create KiCAD files
2026-05-14 Rename PCB/iterations/third/Production Files to PCB/iterations/third/ProductionFiles/test
